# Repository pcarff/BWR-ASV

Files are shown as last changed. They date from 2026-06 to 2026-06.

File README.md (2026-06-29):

# Project Blue-Water Rover (BWR) ASV

Project Blue-Water Rover is a long-range, solar-assisted Autonomous Surface Vehicle (ASV) engineered to navigate an unassisted ocean voyage from Charleston, SC, around the Florida Keys, to Tampa Bay, FL (approximately 650–700 nautical miles). 

This repository contains the physical specifications, control system architectures, telemetry protocol definitions, and an interactive mission control simulator for the vessel.

---

## 1. System Overview

### 1.1 Hydro-Stabilized Catamaran (Option F)
The vessel utilizes a true catamaran hull configuration optimized for seaworthiness, low hydrodynamic drag, and high solar panel surface area:
*   **Hulls**: Dual 6-inch SDR-35 PVC pontoons (2.53m length) spaced 800mm center-to-center, floating at a safe and efficient 50\% draft.
*   **Stability**: Swept-back aluminum foil keel fin (45° rake angle) terminating in a submerged 15 kg solid lead ballast bulb. This configuration provides a powerful recovery righting moment for automated self-righting during capsize without housing any sensitive electronics underwater.
*   **Propulsion**: Dual transom-mounted BlueRobotics T200 brushless underwater thrusters. Directional steering is achieved entirely via differential thrust (rudderless), eliminating mechanical steering linkages.
*   **Power**: An 800W deck-mounted monocrystalline flexible solar array split into dual independent MPPT charging circuits feeding a deck-mounted 48V  115Ah LiFePO4 battery bank.

### 1.2 Three-Tier Control Stack Architecture
The onboard avionics are isolated into independent tiers to guarantee core navigation and survival even during software lockups or perception reboots:
1.  **Tier 1: Perception & Decision (Jetson Orin Nano)**: Processes 3D depth feeds from an **Intel RealSense D455** depth camera using ROS2. Responsible for COLREGs obstacle avoidance. Powered ON/OFF dynamically by the Pi to conserve energy.
2.  **Tier 2: Companion & Telemetry Hub (Raspberry Pi 4 Model B)**: Operates 24/7. Manages communication routing, processes incoming command frames, transmits diagnostics, and handles power state switching.
3.  **Tier 3: Navigation & Actuation (Pixhawk 6X)**: Runs PX4 or ArduPilot on a real-time RTOS. Performs sensor fusion and attitude/heading control. Connects to **Dual Holybro F9P RTK-GPS** modules to calculate heading using GPS carrier-phase yaw, bypassing compass magnetic interference.
4.  **Tier 0: Environmental Watchdog (Arduino Nano)**: Monitors watertight enclosure temperature/humidity and leak sensors. Automatically power-cycles companion compute rails via MOSFET switches if a watchdog heartbeat is lost.

---

## 2. Directory Layout & Document Map

### 2.1 File Structure
```
├── comms/                       # Python telemetry handler & test suites
│   ├── telemetry_handler.py     # XOR-checksummed ASCII packet parser & watchdog
│   └── test_telemetry.py        # Telemetry testing script
├── docs/                        # Specifications, comparisons, and design notes
│   ├── asv_option_f_spec.md     # Catamaran Option F primary design specification
│   ├── asv_vessel_design.md     # Comparative hull designs (Option A to E)
│   ├── comms_protocol.md        # UART serial packet specs & MeshCore setup
│   ├── spec.md                  # Initial draft spec and solar power balance math
│   └── vessel_assessment_recommendations.md  # Structural evaluation & historical studies
├── index.html                   # Mission Control Dashboard & Simulator webpage
├── app.js                       # Frontend simulation logic & physics engine
├── style.css                    # Dashboard interface styles
├── pvc_extrusion_bracket.scad   # Parametric 3D-printable hull mounting bracket code
└── README.md                    # Project landing page (this document)
```

### 2.2 Core Documentation Links
Detailed engineering specifications and design justifications are linked below:
*   [Option F Specification (docs/asv_option_f_spec.md)](file:///workspaces/BWR_ASV/docs/asv_option_f_spec.md): Complete mechanical details, updated BOM, and step-by-step assembly instructions.
*   [Vessel Design Study (docs/asv_vessel_design.md)](file:///workspaces/BWR_ASV/docs/asv_vessel_design.md): Deep-dive analysis of monohull vs. catamaran hydrodynamics and solar deck layouts.
*   [Telemetry Protocol Spec (docs/comms_protocol.md)](file:///workspaces/BWR_ASV/docs/comms_protocol.md): Serial packet framing, duplicate echo suppression, and MeshCore AES-256 CLI configurations.
*   [Systems Engineering Recommendations (docs/vessel_assessment_recommendations.md)](file:///workspaces/BWR_ASV/docs/vessel_assessment_recommendations.md): Comparative reviews of historical transoceanic crossings (*SeaCharger* & *SunChallenger II*) and PVC weight-to-buoyancy evaluations.
*   [Avionics Hardware Architecture](file:///home/pcarff/.gemini/antigravity-ide/brain/0ac91ee5-cb3c-4ac3-8ae8-dadeb8bd1fae/hardware_architecture.md): The detailed block diagram, component roles, interface matrix, and power state transitions.

---

## 3. Mission Control Dashboard & Simulator

This repository contains an interactive, web-based simulation tool to validate propulsion power draw, solar energy harvesting, battery depleting curves, and waypoint tracking under varying conditions:

1.  Open the [index.html](file:///workspaces/BWR_ASV/index.html) file in a modern web browser.
2.  Adjust the **Weather System** (Sunny, Overcast, Storm Front, Night) to simulate changes in solar panel efficiency.
3.  Modify the **Simulation Speed** (1x to 60x time lapse) to fast-forward the voyage.
4.  Monitor the live diagnostic telemetry panel, showing real-time battery SoC %, thruster outputs, coordinate tracking, and serial command frames.

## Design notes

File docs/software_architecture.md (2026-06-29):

# Software Architecture & Control System Guide
## Project Blue-Water Rover (BWR) ASV
## Target Audience: Middle School Students to Senior Systems Engineers

Welcome to the control system guide for the Blue-Water Rover (BWR) Autonomous Surface Vehicle (ASV)! This guide explains how the software codebase in the [/src/](file:///workspaces/BWR_ASV/src/) folder works, which hardware runs which code, and how to set up and deploy the system.

---

## 1. High-Level Concept: The Robotics Analogy

To understand how our software works, we can compare the different code files to parts of a human body or an RC pilot:

| Code File | Robotic Part | Human Analogy | What it does |
| :--- | :--- | :--- | :--- |
| [main.py](file:///workspaces/BWR_ASV/src/main.py) | **The Brain** | Central Nervous System | Coordinates all components, decides between auto/manual modes, and serves the HUD dashboard. |
| [spektrum_rc.py](file:///workspaces/BWR_ASV/src/spektrum_rc.py) | **The Reflexes** | Listening for instructions | Listens to a human pilot holding a Spektrum remote control. |
| [navigation.py](file:///workspaces/BWR_ASV/src/navigation.py) | **The Map & Compass** | Inner Ear & Navigation sense | Reads NMEA GPS strings, figures out where the target is, and calculates how much to steer the rudder. |
| [perception.py](file:///workspaces/BWR_ASV/src/perception.py) | **The Eyes** | Depth Vision | Scans the water using an Intel RealSense D455 depth camera to see if any obstacles are in the way. |
| [drive_control.py](file:///workspaces/BWR_ASV/src/drive_control.py) | **The Muscles** | Hands on the steering wheel | Sends electrical Pulse Width Modulation (PWM) signals to push the motor and turn the rudder. |

---

## 2. Hardware-to-Software Deployment Map

The ASV splits its computational workload across four hardware components to ensure safety, speed, and energy efficiency.

```
+---------------------------------------------------------------------------------+
|                         HARDWARE SOFTWARE DEPLOYMENT MAP                        |
+---------------------------------------------------------------------------------+
| Device            | Operating System (OS)     | Code Files / Software Running   |
+-------------------+---------------------------+---------------------------------+
| Raspberry Pi 4 B  | Raspberry Pi OS Lite (64) | main.py, spektrum_rc.py,        |
|                   |                           | navigation.py, drive_control.py |
|                   |                           | (fallback), telemetry_handler.py|
+-------------------+---------------------------+---------------------------------+
| Jetson Orin Nano  | NVIDIA JetPack SDK        | perception.py                   |
|                   | (Ubuntu Linux 20.04/22.04)| Intel RealSense SDK (pyrealsense)|
+-------------------+---------------------------+---------------------------------+
| Pixhawk 6X        | NuttX RTOS (PX4/ArduPilot)| ArduPilot (ArduRover Firmware)  |
|                   |                           | EKF3 Att/Pos Estimation, Servo  |
+-------------------+---------------------------+---------------------------------+
| Arduino Nano      | Bare-Metal (No OS)        | watchdog.ino                    |
|                   |                           | (Watchdog & leak sensor loop)   |
+-------------------+---------------------------+---------------------------------+
```

---

## 3. Physical Inter-Connection Diagram

The following diagram illustrates how the computing boards, sensors, power lines, and actuators connect.

```
       +--------------------+
       |  Intel RealSense   |
       |    D455 Camera     |
       +---------+----------+
                 | (USB 3.0 Shielded)
                 v
       +--------------------+            (Gigabit Ethernet RJ45)           +--------------------+
       |  Jetson Orin Nano  |<============================================>|  Raspberry Pi 4 B  |
       |  (12V Power In)    |                                              |  (5V Power In)     |
       +---------+----------+                                              +------+---+---+--+--+
                 ^                                                                |   |   |  |  |
                 | (12V Switched Power Rail)                                      |   |   |  |  |
                 |                                                                |   |   |  |  | (5V Switched Rail)
        +--------+--------+                                  (I2C: SDA/SCL)       |   |   |  |  +------+
        | MOSFET Switches |<------------------------------------------------------+   |   |  |         |
        +--------+--------+                                  (Heartbeat GPIO)         |   |  |         |
                 ^                                                                    |   |  |         |
                 | (Gate Signals)                                                     |   |  |         |
       +---------+----------+                                                         |   |  |         |
       | Arduino Nano       |<--------------------------------------------------------+   |  |         |
       | (5V Awake 24/7)    |                                                             |  |         |
       +---+---+------------+                                                             |  |         |
           |   |                                                                          |  |         |
           |   +--------> SHT31 Humidity & Leak Probes                                    |  |         |
           +------------> 5V Relay -> Bilge Pump                                          |  |         |
                                                                                          |  |         |
       +--------------------+                         (MAVLink Serial / UART)             |  |         |
       | Pixhawk 6X         |<------------------------------------------------------------+  |         |
       | (5.3V via PM)      |                                                                |         |
       +---+---+------------+                                                                |         |
           |   |                                      (Spektrum Serial RX / GPIO 15)         |         |
           |   +--------> Dual H-RTK F9P GPS                                                 |         |
           |                                                                                 |         |
           +------------> PWM Main 1 -> Rudder Servo                                         |         |
           +------------> PWM Main 2 -> Drive Motor ESC                                      |         |
                                                                                             |         |
       +--------------------+                                                                |         |
       | Heltec V3 (LoRa)   |<---------------------------------------------------------------+         |
       +--------------------+                                                                          |
                                                                                                       |
       +--------------------+                                                                          |
       | RockBLOCK 9603     |<-------------------------------------------------------------------------+
       | (Iridium Satellite)|
       +--------------------+
```

---

## 4. Software Setup & Installation Instructions

This section outlines step-by-step instructions to configure each piece of hardware from scratch.

### 4.1 Raspberry Pi 4 B (The Systems Manager)
The Pi 4 coordinates communications and handles the main loop.

#### 1. OS Installation
1.  Download and open the **Raspberry Pi Imager** on a computer.
2.  Choose **Raspberry Pi OS Lite (64-bit)** (debian bookworm base, contains no graphical desktop interface to save RAM and power).
3.  Set host name to `bwr-pi` and enable **SSH** with a secure password or SSH key.
4.  Configure Wi-Fi details (for local yard testing) and flash the SD card.

#### 2. Serial & GPIO Configuration
Once booted, log into the Pi via SSH (`ssh pi@bwr-pi.local`) and execute:
1.  Run the config tool: `sudo raspi-config`.
2.  Navigate to **Interface Options** $\rightarrow$ **Serial Port**.
3.  Select **No** to *"Would you like a login shell to be accessible over serial?"* and **Yes** to *"Would you like the serial port hardware to be enabled?"*.
4.  Save and exit.
5.  Edit `/boot/firmware/config.txt` (or `/boot/config.txt`) to release UART0 for Spektrum serial:
    ```bash
    sudo nano /boot/firmware/config.txt
    # Append the following line to disable bluetooth overlays binding to UART
    dtoverlay=disable-bt
    ```
6.  Reboot the Pi: `sudo reboot`.

#### 3. Install Dependencies
```bash
# Update package list
sudo apt-get update && sudo apt-get upgrade -y

# Install Python package manager and Git
sudo apt-get install -y python3-pip python3-dev git pigpio python3-pigpio

# Start and enable the pigpio daemon (for hardware PWM)
sudo systemctl enable pigpiod
sudo systemctl start pigpiod

# Install python libraries
pip3 install pyserial flask pynmea2
```

#### 4. Auto-Start Service Configuration
To ensure the autopilot code starts automatically whenever the battery vault powers on:
1.  Create a systemd service file:
    ```bash
    sudo nano /etc/systemd/system/bwr_autopilot.service
    ```
2.  Paste the following configuration:
    ```ini
    [Unit]
    Description=Blue-Water Rover Autopilot Stack
    After=network.target pigpiod.service
    Requires=pigpiod.service

    [Service]
    ExecStart=/usr/bin/python3 /workspaces/BWR_ASV/src/main.py
    WorkingDirectory=/workspaces/BWR_ASV/src
    StandardOutput=inherit
    StandardError=inherit
    Restart=always
    User=root

    [Install]
    WantedBy=multi-user.target
    ```
3.  Enable and start the service:
    ```bash
    sudo systemctl daemon-reload
    sudo systemctl enable bwr_autopilot.service
    sudo systemctl start bwr_autopilot.service
    ```

---

### 4.2 Jetson Orin Nano (Perception Computer)
The Jetson processes depth images from the RealSense camera.

#### 1. OS Installation
1.  Download **NVIDIA JetPack 5.x / 6.x** matching the developer kit.
2.  Flash the JetPack OS image onto a fast NVMe SSD or SD card using NVIDIA SDK Manager or Balena Etcher.
3.  Complete the initial Ubuntu setup wizard, creating user `bwr-jetson`.

#### 2. Installing Intel RealSense SDK (librealsense)
Set up NVIDIA repositories and build/install the camera drivers:
```bash
# Register NVIDIA key and repo
sudo apt-key adv --keyserver keyserver.ubuntu.com --recv-key F6E65AC044F831AC80A06380C8B3A55A6F88E2D9
sudo add-apt-repository "deb https://librealsense.intel.com/Debian/apt-repo $(lsb_release -cs) main" -u

# Install library
sudo apt-get install -y librealsense2-utils librealsense2-dev

# Install python bindings
pip3 install pyrealsense2 numpy opencv-python
```

#### 3. Running the Perception Script
Verify the RealSense camera works by running the python pipeline directly:
```bash
python3 /workspaces/BWR_ASV/src/perception.py
```

---

### 4.3 Pixhawk 6X (Autopilot)
The Pixhawk runs the low-level motor loops and coordinates the GPS.

#### 1. Firmware Flash
1.  Download and install **QGroundControl** on a ground station laptop.
2.  Connect the Pixhawk 6X to the laptop using a USB-C cable.
3.  Go to **Vehicle Setup** $\rightarrow$ **Firmware**.
4.  Select **ArduPilot** $\rightarrow$ **Rover** (ArduRover stable release) and click **OK** to flash.

#### 2. Parameter Tuning (via QGroundControl)
Once flashed, configure parameters to support the single motor + rudder layout:
*   `FRAME_CLASS` = `2` (Rover class).
*   `MOT_TYPE` = `0` (Normal steering and throttle outputs).
*   `SERVO1_FUNCTION` = `26` (Ground Steering - maps rudder PWM to Output port 1).
*   `SERVO3_FUNCTION` = `70` (Throttle - maps ESC PWM to Output port 3).
*   `SERIAL1_PROTOCOL` = `2` (MAVLink 2 - enables telemtry comms with Pi on TELEM1 port).
*   `SERIAL1_BAUD` = `115` (115200 baud).
*   `GPS_TYPE` = `2` (RTK GPS configuration on port GPS1).
*   `GPS_TYPE2` = `2` (Second GPS unit on GPS2 for GPS-for-yaw calculations).

---

### 4.4 Arduino Nano (Safety Monitor)
The Arduino stays powered on 24/7 to monitor safety metrics and power-cycle computers.

#### 1. Hardware Pin Mapping
*   **A0**: Leak Sensor Probe 1 (Avionics Box)
*   **A1**: Leak Sensor Probe 2 (Battery Box)
*   **Pin 2 (Input)**: Heartbeat signal from Pi 4 GPIO.
*   **Pin 4 (Output)**: MOSFET Gate 1 (controls Pi 4 power supply).
*   **Pin 5 (Output)**: MOSFET Gate 2 (controls Jetson power supply).
*   **Pin 6 (Output)**: Relay drive (controls Bilge Pump power line).

#### 2. Watchdog Firmware Setup
Write the following watchdog sketch to the Arduino Nano using the **Arduino IDE**:

```cpp
#include <Arduino.h>

const int PIN_HEARTBEAT = 2;
const int PIN_GATE_PI = 4;
const int PIN_GATE_JETSON = 5;
const int PIN_BILGE = 6;
const int PIN_LEAK_1 = A0;
const int PIN_LEAK_2 = A1;

unsigned long last_heartbeat_time = 0;
bool last_hb_state = false;

void setup() {
  pinMode(PIN_HEARTBEAT, INPUT);
  pinMode(PIN_GATE_PI, OUTPUT);
  pinMode(PIN_GATE_JETSON, OUTPUT);
  pinMode(PIN_BILGE, OUTPUT);
  
  // Power on computing boards by default
  digitalWrite(PIN_GATE_PI, HIGH);
  digitalWrite(PIN_GATE_JETSON, HIGH);
  digitalWrite(PIN_BILGE, LOW); // Keep bilge pump off
  
  last_heartbeat_time = millis();
}

void loop() {
  bool current_hb = digitalRead(PIN_HEARTBEAT);
  
  // Reset watchdog if heartbeat edge detected
  if (current_hb != last_hb_state) {
    last_heartbeat_time = millis();
    last_hb_state = current_hb;
  }
  
  // 1. Pi Watchdog: If Pi is frozen for > 45 seconds, cold reboot it
  if (millis() - last_heartbeat_time > 45000) {
    // Cut Pi power
    digitalWrite(PIN_GATE_PI, LOW);
    delay(5000);
    // Restore Pi power
    digitalWrite(PIN_GATE_PI, HIGH);
    last_heartbeat_time = millis();
  }
  
  // 2. Leak Detection
  int leak_val_1 = analogRead(PIN_LEAK_1);
  int leak_val_2 = analogRead(PIN_LEAK_2);
  
  // Analog threshold: raw water contact pulls values below 300
  if (leak_val_1 < 300 || leak_val_2 < 300) {
    // Leak detected! Start bilge pump
    digitalWrite(PIN_BILGE, HIGH);
  } else {
    // Dry condition, turn pump off
    digitalWrite(PIN_BILGE, LOW);
  }
  
  delay(100);
}
```
3.  In the Arduino IDE, select **Board: Arduino Nano** and click **Upload** to burn the watchdog loop.

---

## 5. How the Key Code Components Work

### 5.1 Reading the Remote Control: Serial Sync & Bit Shifting
**Middle School View**: The remote control transmitter sends wireless packets to a receiver on the boat. The receiver repeats these messages to our computer. Because characters can get jumbled in translation, the code waits for a "quiet moment" in the conversation (a time gap of 5 milliseconds) to know a new instruction package has begun.

**Senior Engineer View**: The Spektrum Satellite serial protocol operates at 115200 baud, sending 16-byte frames containing 7 proportional channels. Since UART is an asynchronous byte stream, aligning bytes requires a frame synchronization heuristic. The parser tracks byte arrival times; if `current_time - last_byte_time > 0.005` seconds, the buffer is flushed and the next byte is marked as byte 0.

Each channel is parsed as a 2-byte big-endian word:
```python
# Extract channel ID and 11-bit value from DSMX frame word
chan_id = (word >> 11) & 0x0F
value = word & 0x07FF  # values from 0 to 2047
```
If no valid frame arrives for 1.0 second, a connection watchdog triggers a safety fallback, centering the rudder and cutting throttle to neutral.

### 5.2 Autopilot Steering: PID Control
**Middle School View**: Imagine walking down a path toward a target flag. If a gust of wind blows you to the left, your brain senses the error and tells your legs to steer right. The closer you get, the less you need to correct. Our boat does this with a math formula called **PID (Proportional, Integral, Derivative) Control** to decide how much to turn the rudder:
*   **Proportional (P)**: Turn more if the heading error is large.
*   **Integral (I)**: Turn extra if wind or waves have been pushing us off-course for a long time.
*   **Derivative (D)**: Counter-steer to slow down the turn as we approach the correct direction, preventing the boat from zig-zagging.

**Senior Engineer View**: The navigation controller uses the Haversine formula to compute the distance $d$ and initial bearing $\theta_{bearing}$ between the boat $(Lat_1, Lon_1)$ and target waypoint $(Lat_2, Lon_2)$. The heading error is computed relative to the Course Over Ground (COG) and wrapped to $[-180, 180]$ degrees:
```python
heading_error = target_bearing - current_cog
heading_error = (heading_error + 180) % 360 - 180
```
The PID loop calculates the rudder correction:
$$u(t) = K_p \cdot e(t) + K_i \int e(t)dt + K_d \frac{de(t)}{dt}$$
*   **Anti-Windup**: The integral error sum is clamped to $[-30, 30]$ degrees to prevent integrator saturation during long turns.
*   **Output**: The final steering fraction $u(t)$ is clamped to $[-1.0, 1.0]$ representing full left/right rudder deflection.

### 5.3 Obstacle Avoidance: RealSense Proximity Grid
**Middle School View**: The Intel RealSense camera works like a bat's ears, but uses light instead of sound. It shines invisible infrared patterns and measures how long it takes for the patterns to bounce back. The code cuts this visual image into three vertical blocks: **Left**, **Center**, and **Right**. If an object appears closer than 8 meters, the autopilot swerves in the opposite direction.

**Senior Engineer View**: We stream depth buffers at a $640 \times 480$ resolution. To avoid water-surface glint (reflections) and sky noise, the scan checks only pixels in the vertical center band ($160 \le y \le 320$). The columns are partitioned into three sectors: Left $[0, 213]$, Center $[214, 426]$, and Right $[427, 639]$. 

If an obstacle is detected in the Center sector at a distance $D_{center} < D_{avoid}$:
*   Compare Left and Right sectors.
*   Apply steering offset offset toward the clearer side:
    $$\theta_{avoid} = \pm 0.8 \cdot \left(1.0 - \frac{D_{center}}{D_{avoid}}\right)$$
*   If the center obstacle distance drops below 4.0 meters, the drive controller triggers an emergency reverse throttle fraction ($-0.2$) to back off.

### 5.4 Motor Control: Pulse Width Modulation (PWM)
**Middle School View**: How do we tell an electric motor how fast to spin, or a rudder motor what angle to hold? We send them tiny pulses of electricity. A 1.5 millisecond pulse (1500 microseconds) means "stop" or "center". A longer pulse (2000 microseconds) means "full speed forward" or "turn right". A shorter pulse (1000 microseconds) means "full speed backward" or "turn left". Repeating this pulse 50 times every second is called Pulse Width Modulation.

**Senior Engineer View**: The Pi uses the `pigpio` library to generate hardware-timed PWM signals via the DMA (Direct Memory Access) controller. This bypasses Linux kernel execution scheduling jitter, preventing the rudder servo from vibrating or twitching. 
*   **Current Protection Slew Limit**: Sudden throttle changes from 0% to 100% can draw massive current spikes, potentially crashing the computers. The drive controller applies a rate-limit (slew rate) of $500\text{ us/second}$, forcing the throttle output to ramp up smoothly over 1.0 second.

---

## 6. The HUD Mission Control Web Dashboard

To monitor the boat in real-time, the system starts a Flask web server on port 5000:
1.  **Backend (Python)**: `main.py` hosts a JSON API `/api/telemetry` which aggregates variables from the RC, GPS, Navigation, and RealSense threads, and `/api/command` which accepts commands from the browser.
2.  **Frontend (HTML/CSS/JS)**: Accessing `http://<pi_ip>:5000/` loads the glassmorphic dark-mode HUD dashboard:
    *   **Circular gauges** render battery capacity and solar power levels.
    *   **Rotating needles** show heading and bearings.
    *   **Sonar indicators** glow red if obstacles approach.
    *   An **SVG projection** maps the coordinates of the boat onto the coastline map.

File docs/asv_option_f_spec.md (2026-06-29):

# Design Specification Document (ESD-01-F)
## Project Blue-Water Rover: Option F (Hydro-Stabilized Ocean Catamaran)
## Revision: 1.0

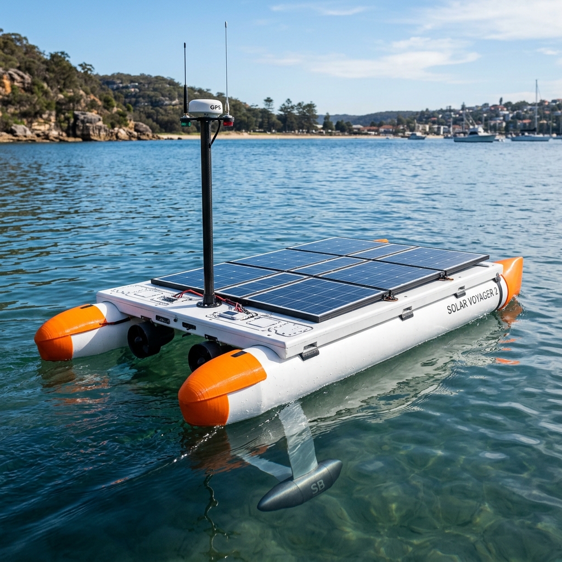
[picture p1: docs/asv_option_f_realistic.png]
Option F Hydro-Stabilized Ocean Catamaran


This document outlines the detailed mechanical, electrical, and telemetry specifications for the Option F (Hydro-Stabilized Ocean Catamaran) configuration of the Blue-Water Rover ASV. Option F is a highly refined, seaworthy hybrid design incorporating the lessons of historical transoceanic crossings and resolving the critical structural, waterproofing, and steering vulnerabilities of Option E. It is optimized for a 650–700 NM open-ocean voyage from Charleston, SC, to Tampa Bay, FL, while remaining constructible within a standard apartment workshop using off-the-shelf PVC, 2020 extrusions, and 3D printing.

---

## 1. Physical & Hydrodynamic Specifications

### 1.1 Dimensions & Hull Layout
*   **Outboard Pontoons**: Dual 6-inch (150mm nominal / 159.4mm OD) SDR-35 PVC pipes, 2.53m length, spaced **800mm center-to-center** (overall beam width of 1.0m at the frame, and 1.2m including the hulls).
    *   *Sizing Caution*: 6" SDR-35 has an OD of **159.4 mm (6.275 in)** compared to 6" Schedule 40's **168.3 mm (6.625 in)**. Standard Schedule 40 slip-on caps will not fit SDR-35. Custom caps must be 3D-printed with a 159.4 mm ID, and bracket dimensions must be set to `pvc_od = 159.4` in the OpenSCAD models to ensure a secure fit.
*   **Aerodynamic Bow Caps**: Custom 3D-printed **ASA** nose cones cemented to the front of each PVC pontoon. The bows feature a sharp, wave-piercing entry profile designed to slice through swells and prevent seaweed accumulation.
*   **Swept-Back Foil Keel Fin**: A high-strength, swept-back flat metal foil plate (6061-T6 aluminum or 316 stainless steel, 8mm thickness, 400mm height) slung centerline. The fin is swept back at a **45° rake angle** so sargassum, weeds, and fishing lines naturally slide down and shed off the bottom.
*   **Submerged Lead Ballast Bulb**: A compact, streamlined lead bulb (100mm diameter, 500mm length, slung at z = -450mm below the water line). Weight: **15.0 kg** of solid lead ballast encased in a fiberglass/epoxy protective shroud with a 3D-printed ASA nose/tail cone. The bulb contains **zero electrical or chemical components**.
*   **Solar Deck Size**: 1.4m width  x  2.0m length (2.8 m²) made of 4mm white Coroplast sheets secured to 2020 aluminum rails. The deck overhangs the frame by 200mm on both sides.
*   **Total Dry Mass**: ~ 96.5 kg (Payload: 85 kg + Hulls/Frame: 11.5 kg).
*   **Hydrodynamic Draft**: **~ 50–53\%** under full 96.5 kg load (waterline at the vertical center of the hulls). 
    *   *Justification*: By moving the 35 kg battery vault to the deck and spacing the hulls apart, the boat floats at its hydrodynamic sweet spot. This keeps the overhanging solar deck clean of splashes, minimizes wave-making resistance, and avoids solar cell shading.

### 1.2 Self-Righting & Stability Physics
*   **Center of Buoyancy (B)**: Located near the centerline at the waterline (z ~ -84mm).
*   **Center of Gravity (G)**: Located at z ~ -180mm. By hanging a 15 kg lead bulb at z = -450mm, the Center of Gravity is pulled well below the Center of Buoyancy despite the battery bank being mounted on the deck.
*   **Auto-Recovery Righting Moment**: If rolled past 90° or completely capsized (180°), the 15 kg lead ballast creates a powerful self-righting torque (Righting Arm GZ ~ 270mm). The buoyancy of the closed, empty PVC hulls pushes upward while the lead weight pulls downward, immediately self-righting the vessel. The overhanging Coroplast deck is designed with a slight camber (curved arch) to prevent water pooling and ensure it sheds water instantly during recovery.

---

## 2. Power & Electrical Architecture

### 2.1 Deck-Mounted Watertight Power Vault
*   **Battery Relocation**: The 48V  115Ah LiFePO4 battery bank (35 kg) is housed in a heavy-duty, IP67-rated polycarbonate enclosure mounted securely on the **aft-left deck**, directly over the structural aluminum frame.
*   *Safety & Thermal Design*: Moving the batteries out of the submerged bulb keeps them completely free of hydrostatic pressure risks. The box is equipped with a Gore-Tex breathing vent to prevent pressure differences due to temperature changes and contains non-flammable packing foam to secure the cells.
*   *Avionics Isolation*: High-voltage power lines are run in shielded conduits. The edge autopilot and LoRa/satellite electronics are housed in a **separate IP67 box on the aft-right deck** to isolate sensitive signals from high-current electrical noise.

### 2.2 Solar Array & Charging Redundancy
*   **Solar Array**: Eight 100W flexible monocrystalline solar panels (540mm  x  1050mm) arranged in a 4x2 grid on the flat Coroplast deck.
*   **Redundant Dual MPPT**: The array is split into two independent 400W charging circuits:
    *   *Circuit 1*: Left-side panels (4 panels) connected to **Victron SmartSolar MPPT 75/15 #1**.
    *   *Circuit 2*: Right-side panels (4 panels) connected to **Victron SmartSolar MPPT 75/15 #2**.
    *   *Justification*: If the sensor mast casts a shadow on one side of the boat, or if one solar controller fails, the other side continues harvesting power at full efficiency, maintaining battery charging.

---

## 3. Propulsion & Steering (Rudderless Redundancy)

*   **Dual Transom-Mounted Thrusters**: Two BlueRobotics T200 brushless underwater thrusters mounted directly to the stern transoms of the left and right PVC pontoons (spaced exactly 800mm apart).
*   **Motor Construction**: Fully potted stators with water-lubricated ceramic bearings. No dynamic shaft seals or oil-filled chambers, completely eliminating water ingress and wear issues.
*   **Rudderless Differential Steering**: Directional control is achieved entirely by varying the thrust difference between the left and right motors:
    omega  proportional to  (T_right - T_left)  *  0.8m
*   **Redundancy Analysis**: 
    *   *Rudder Elimination*: By removing the mechanical rudder, Savox steering servo, linkages, and rubber sealing boot, we eliminate the primary failure point seen in *SeaCharger*.
    *   *Failure Tolerance*: If one thruster fails due to debris or motor lockout, the autopilot enters a **Single-Thruster Safe-Return Mode**, pulsing the remaining thruster and using short reverse thrust cycles to crab/steer the vessel back to the nearest coastal waypoint using the satellite link.

---

## 4. Telemetry & Communications

*   **Three-Tier Avionics Core**:
    *   *High-Level Perception (Jetson Orin Nano)*: Runs Ubuntu, ROS2, and custom depth-clustering/YOLO models to process 3D depth feeds from the Intel RealSense D455 camera for COLREGs obstacle avoidance. Powered ON/OFF dynamically.
    *   *System Companion (Raspberry Pi 4 Model B)*: Runs 24/7. Manages telemetry parsing, interfaces with cellular/satellite/LoRa modems, and duty-cycles power to the Jetson.
    *   *Autopilot Core (Pixhawk 6X)*: Runs an RTOS (ArduPilot/PX4). Handles low-level differential thruster steering PID loops, navigation waypoints, and sensor fusion.
    *   *Safety Supervisor (Arduino Nano)*: Minimal power watchdog board. Polls environmental sensors (leaks/humidity) and can power-cycle frozen compute boards.
*   **Multi-Link Telemetry Suite**:
    *   *Primary Coastal (MeshCore LoRa)*: Heltec V3 node operating at 915 MHz for ground station links up to 45 NM offshore.
    *   *High-Speed Local (5G Modem)*: USB dongle connected to the Pi 4 for high-bandwidth remote operations near ports.
    *   *Backup Satellite (RockBLOCK 9603 Iridium)*: Global satellite transceiver transmitting diagnostic heartbeats and emergency commands in deep ocean.
*   **Dual GPS-for-Yaw**: Dual Holybro H-RTK F9P GPS units spaced longitudinally on the frame. Calculates GPS-based heading (carrier-phase differential) to eliminate electromagnetic compass interference.
*   **System Power Consumption**: Draws ~ 6.0 W in Transit Mode (Pi 4 + Pixhawk + Comms active) and peaks at ~ 20.5 W in Avoidance Mode (Jetson + D455 fully active).

---

## 5. Apartment-Scale Bill of Materials (BOM)

| Component Category | Description | Qty | Est. Cost |
| :--- | :--- | :--- | :--- |
| **Outboard Pontoons** | 6-inch SDR-35 Thin-Walled PVC Sewer Pipe (10 ft length) | 2 | \$60 |
| **Outboard Pontoons** | 6-inch PVC Domed End-Caps (Stern only) | 2 | \$20 |
| **Keel Foil & Ballast** | 8mm 6061-T6 Aluminum Plate (machined hydrofoil) | 1 | \$60 |
| **Keel Foil & Ballast** | Cast Lead Ballast Weight (15 kg, streamlined cylinder) | 1 | \$45 |
| **3D Printed Parts** | Custom single-nosed 6" pontoon bow caps (ASA) | 2 | \$30 (filament) |
| **3D Printed Parts** | Keel root connection block & foil clamp (ASA) | 1 | \$20 (filament) |
| **Structure** | 2020 (20mm x 20mm) T-Slot Anodized Aluminum Extrusions | 6 | \$80 |
| **Deck** | 4mm White Coroplast Sheet (1.4m  x  2.0m) | 1 | \$25 |
| **Power** | 48V 115Ah LiFePO4 battery cells (cylindrical) | 16 | \$900 |
| **Power** | IP67 Heavy-Duty Polycarbonate Enclosures (Deck Boxes) | 2 | \$70 |
| **Power** | Victron SmartSolar MPPT Charge Controller | 2 | \$160 |
| **Solar** | Renogy 100W Flexible Solar Panel | 8 | \$800 |
| **Propulsion** | BlueRobotics T200 Brushless Thruster | 2 | \$500 |
| **Electronics** | Pixhawk 6X Flight Controller & Power Module | 1 | \$380 |
| **Electronics** | Raspberry Pi 4 Model B (4GB) | 1 | \$55 |
| **Electronics** | Jetson Orin Nano Developer Kit (8GB) | 1 | \$399 |
| **Electronics** | Arduino Nano (3.3V) & MOSFET power board | 1 | \$25 |
| **Electronics** | Intel RealSense D455 Depth Camera (with IP67 dome housing) | 1 | \$380 |
| **Electronics** | Dual Holybro H-RTK F9P GPS Units | 2 | \$440 |
| **Telemetry** | Heltec V3 LoRa + RockBLOCK 9603 + USB 5G Modem | 1 | \$420 |
| **Total Est. Cost**| | | **\$4,870** |

---

## 6. Assembly & Construction Instructions

1.  **Hull Preparation**: Cut the two 6-inch SDR-35 PVC pipes to 2.53m. Use PVC primer and cement to secure standard PVC end-caps to the stern transoms. Cement the 3D-printed ASA wave-piercing bow caps to the front of each hull.
2.  **Keel Foil Installation**: Bolt the machined 8mm aluminum foil keel spar to the centerline of the aluminum frame using the 3D-printed root collar. Bolt the 15 kg lead ballast bulb to the bottom of the spar, securing it with locknuts and wrapping it in a thin layer of epoxy fiberglass to prevent galvanic corrosion.
3.  **Frame & Bracket Assembly**: Assemble the 2020 aluminum crossbeams (1.2m width) and long rails (1.9m length). Clamp the frame to the PVC pontoons at 800mm spacing using the custom single-hull mounting brackets cushioned with rubber friction strips.
4.  **Propulsion Mounting**: Bolt the dual BlueRobotics T200 thrusters to the stern transoms of the left and right pontoons. Route the potted power cables along the hulls inside nylon protective conduit and pass them through IP67 glands into the deck boxes.
5.  **Deck and Enclosures Setup**: Mount the 4mm Coroplast deck sheet to the extrusion frame. Bolt the two IP67 deck boxes: the battery vault on the aft-left and the single control avionics box on the aft-right. Secure the LiFePO4 cells inside the battery vault using EPDM foam padding. Mount the Pi 4, Jetson Orin Nano, Pixhawk 6X, and Arduino watchdog inside the control box, ensuring the Jetson heatsink is thermally coupled to the external aluminum heat spreader.
6.  **Solar Array Installation**: Lay out the 8 flexible panels in a 4x2 grid on the deck. Secure them using marine-grade rivets or outdoor zip-ties through the panel eyelets. Route the cables through glands into the avionics box, connecting them to the dual MPPT charge controllers.
7.  **Mast and Camera Setup**: Bolt the 1.2m vertical mast socket to the front center of the aluminum frame. Mount the Intel RealSense D455 in a waterproof dome on the bow or mast. Run the shielded USB 3.0 cable back to the Jetson Orin Nano inside the control box. Mount the dual F9P RTK GPS antennas spaced along the frame, and run their coax cables to the Pixhawk 6X. Route the LoRa, 5G, and Satellite antennas up the carbon fiber mast and connect them to the control box bulkheads.

---

## 7. Rendered Design Views

The following carousel provides multiple high-fidelity perspectives of the Option F design, illustrating the mechanical layout, propulsion configuration, and underwater profile.

````carousel
![Isometric Perspective](./asv_option_f_realistic.png)
<!-- slide -->
![Aft / Transom View (Dual Thrusters)](./asv_option_f_aft_view.png)
<!-- slide -->
![Top-Down Plan View (Blueprint Layout)](./asv_option_f_top_view.png)
<!-- slide -->
![Underwater Side Profile (Swept Keel & Ballast)](./asv_option_f_side_view.png)
````

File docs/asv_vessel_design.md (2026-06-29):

# Systems Engineering & Vessel Design Document
## Project Blue-Water Rover: Long-Range Solar ASV (ESD-01)

This document details the physical, electrical, and computational design of the Blue-Water Rover Autonomous Surface Vehicle (ASV) optimized for an unassisted 650–700 nautical mile voyage from Charleston, SC, to Tampa Bay, FL.

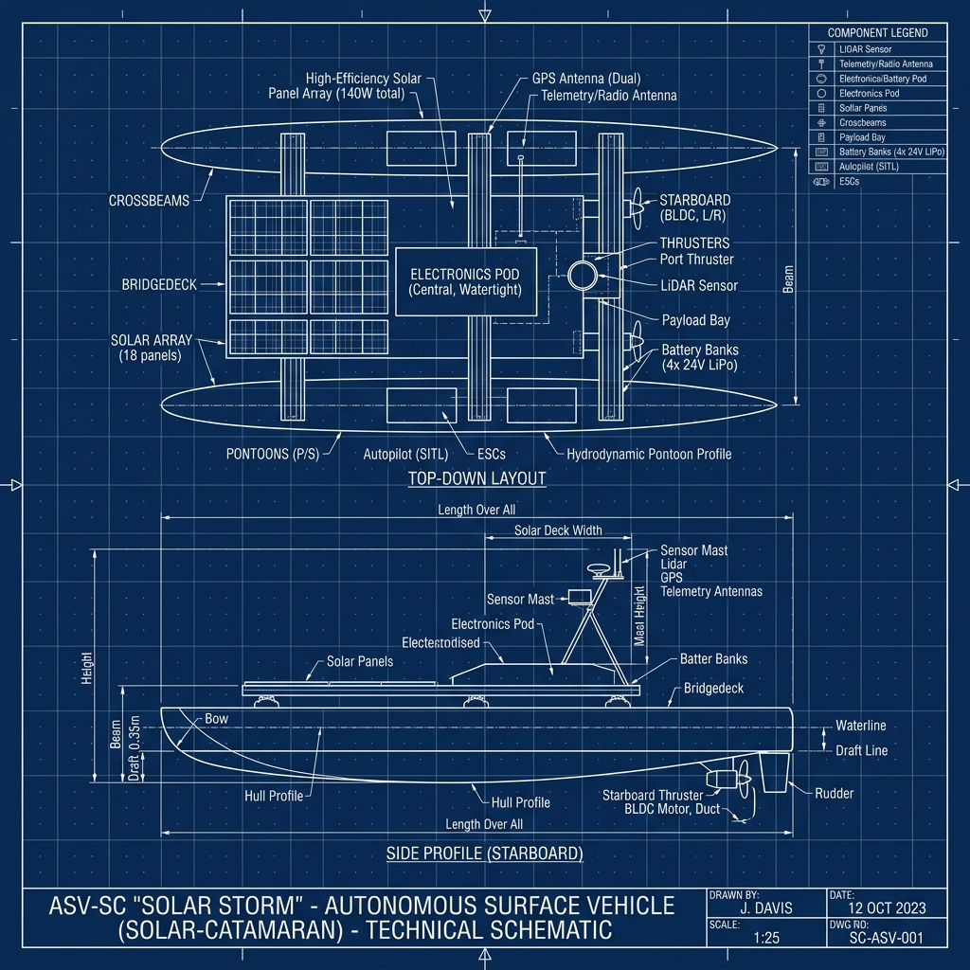
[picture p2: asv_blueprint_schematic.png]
Vessel Design Blueprint Schematic


---

## 1. Hull Selection & Hydrodynamics

Selecting the optimal hull shape represents the fundamental trade-off in solar-electric vessel design. We evaluate three configurations:

| Metric | Monohull (Deep-V) | Catamaran (Dual-Pontoon) | Trimaran (Stabilized Outriggers) |
| :--- | :--- | :--- | :--- |
| **Drag Coefficient (C_d)** | 1.20 (Base) | 0.85 (Low) | 0.75 (Very Low) |
| **Solar Deck Area** | Max 400W | Max 600W | Max 800W |
| **Hull Weight** | 45 kg | 60 kg | 75 kg |
| **Transverse Stability** | Low (Heels in wind/waves) | High (Resists heeling) | Very High (Highly stable) |
| **Wave Roll Sensitivity** | High (Wave action shades panels) | Low (Maintains flat deck) | Minimal (Near-constant solar angle) |

```mermaid
graph TD
    A[Vessel Design Selection] --> B[Monohull]
    A --> C[Catamaran]
    A --> D[Trimaran]
    B --> E[400W Solar Limit / High Drag / High Wave Loss]
    C --> F[600W Solar Limit / Low Drag / Low Wave Loss]
    D --> G[800W Solar Limit / Very Low Drag / Zero Wave Loss]
```

### Recommendation
> [!IMPORTANT]
> The **Catamaran** is selected as the optimal baseline design. It provides a wide, flat deck area to accommodate up to **600W** of flexible solar panels, achieves a **15% reduction in drag** compared to a monohull, and minimizes transverse roll which directly prevents solar panel shading in open water.

---

## 2. Power Architecture & Sizing

The ASV operates on a closed-loop energy cycle. The power balance equation is defined as:
P_net = P_solar  *  eta_mppt - (P_propulsion + P_edge + P_sensors)

### 2.1 Daily Energy Consumption
The continuous power draw for the subsystems is calculated as follows:
* **Edge Compute + Avionics**: 12V  x  1.8A = 21.6W (Pi 5 baseline)
* **Sub-Avionics & Sensors**: 12V  x  0.7A = 8.4W (RTK-GPS, IMU, LoRa transceiver)
* **Propulsion (Cruising Speed)**: 48V  x  1.25A = 60W

P_loads = 21.6W + 8.4W + 60W = 90W
Daily Consumption = 90W  x  24 hours = 2,160 Wh/day

### 2.2 Battery Bank Sizing (LiFePO4)
To ensure system survival during stormy conditions, we design for **2 days of complete autonomy** at a maximum **80% Depth of Discharge (DoD)**:

Required Battery Capacity = (2,160 Wh/day  x  2 days) / (0.8) = 5,400 Wh

Standardized to our 48V system:
Battery Capacity (Ah) = (5,400 Wh) / (48V) = 112.5 Ah
* **Selected Battery**: **48V 115Ah LiFePO4 bank** (5,520 Wh capacity).

### 2.3 Solar Array Sizing & Solar Deficit
Assuming a conservative **5 Peak Sun Hours** per day along the Florida coast, and a **75% efficiency coefficient** (due to panel pitch, splash residue, and temperature losses):

Required Solar Power = (2,160 Wh) / (5 hours  x  0.75) = 576 W

> [!WARNING]
> **The 400W Sizing Gap**: The initial 400W solar panel configuration can generate at most 400W  x  5  x  0.75 = 1,500 Wh/day, leaving a daily deficit of **660 Wh**.
> To resolve this without manual refueling:
> 1. Expand the solar deck area to a **600W array** (requires Catamaran/Trimaran hull).
> 2. Implement **Software Propulsion Throttling** to automatically reduce motor power during low-light/overcast days.

---

## 3. Propulsion & Differential Actuation

The vessel utilizes **dual 48V brushless underwater thrusters** mounted in a differential steering configuration. This eliminates the mechanical failure points of a traditional rudder servo.

```
       [Left Thruster]  =======\
                                \=======> Forward Thrust & Differential Steering
       [Right Thruster] =======/
```

* **Differential Heading Formula**:
  The rate of rotation omega is proportional to the difference in thrust between the left and right thrusters:
  omega  proportional to  (T_right - T_left)  *  L_beam
  Where L_beam is the vessel's beam width.
* **Propulsion Speed Power Curve**:
  V_boat = V_max  *  \sqrt{(P_thrust) / (P_max)}
  A cruise throttle of 60W drives the boat at approximately 5.0 knots.

---

## 4. Edge Avionics & Navigation Stack

The software stack utilizes a hybrid isolation architecture to guarantee system stability:

```
+-------------------------------------------------------------+
|               HIGH-LEVEL MISSION CONTROL (Edge SBC)         |
|   Sensors: RTK-GPS, IMU, Optical Cameras, Radar             |
|   Tasks: COLREGs Avoidance, Path Finding, Telemetry Uplink  |
+-------------------------------------------------------------+
                              | (SPI/UART isolated link)
                              v
+-------------------------------------------------------------+
|              LOW-LEVEL ACTUATOR CORE (STM32 MCU)            |
|   Tasks: Motor throttle PWM, Loiter PID, Keepalive Watchdog |
+-------------------------------------------------------------+
```

### 4.1 Collision Avoidance (COLREGs Compliance)
Using the Edge Compute board, the vessel processes sensory data to avoid coastal marine hazards:
1. **STM32 Only**: Static waypoint follower. No avoidance.
2. **Raspberry Pi 5 / Jetson Orin Nano**: Active vector steering. If an obstacle is detected within 15 NM, the high-level navigator computes an avoidance offset:
   theta_avoid = theta_target + (K_avoid) / (d_obstacle)  *  sign(phi)
   Where d_obstacle is the distance, and phi is the angle to the obstacle center relative to the course.

---

## 5. Telemetry & Communications Mesh

The telemetry system utilizes a low-power **MeshCore LoRa transceiver** operating on the 915 MHz band, configured as a low-power **Companion Node**.

* **Backbone repeater hop network**: 15 onshore mesh repeaters skip telemetry packets from the boat back to the Charleston metro hub command station.
* **Link Budget**:
  - Max direct range: 45 nautical miles over flat ocean water.
  - Frequency: 915 MHz Spread Spectrum (LoRa).
* **Protocol & Commands Specification**:
  - Detailed serial protocol, XOR checksum calculations, and private AES-256 channel configuration commands are documented in the dedicated [Telemetry & Communications Protocol](file:///workspaces/BWR_ASV/docs/comms_protocol.md).
  - Sleep Cycle: The Companion Node wakes up every 10 seconds to check for incoming discrete commands and broadcasts diagnostics upon state change or every 5 minutes.

---

## 6. Vessel Construction Plans

This section serves as the fabrication blueprint and assembly manual for constructing the optimized catamaran ASV.

### 6.1 Mechanical Frame & Hull Integration
1. **Pontoon Preparation**: Select dual rotomolded UV-resistant high-density polyethylene (HDPE) pontoons (length: 2.2m, beam diameter: 0.25m). Mold integrated threaded brass inserts on the upper deck of each pontoon to serve as crossbeam anchor points.
2. **Crossbeam Assembly**: Cut four lengths of 40mm x 40mm T-slot anodized aluminum structural extrusions (80/20 profile). Bolt these crossbeams transversely across the pontoons using M8 marine-grade 316 stainless steel bolts with nylon-insert lock nuts.
3. **Bridge Deck Installation**: Secure a 3.5mm thick carbon-fiber composite sheet across the middle three crossbeams. Apply marine silicone sealant (e.g., 3M Marine Adhesive Sealant 4000UV) along the extrusion channels before fastening to eliminate vibration and squeaking.
4. **Extrusion-to-PVC Mounting Brackets**: For PVC pipe hull options (Options A, B, and C), utilize the 3D-printable parametric mounting brackets designed in [pvc_extrusion_bracket.scad](file:///workspaces/BWR_ASV/pvc_extrusion_bracket.scad). These brackets provide a circular cradle for the PVC pipe, routing slots for metal band hose clamps, and a recessed top slot for bolting down the 2020 aluminum extrusion frame.
   - **Rubber Friction Pad**: Wrap a 1.5mm thick neoprene or EPDM rubber strip around the PVC hull at each bracket junction. The bracket's cradle radius includes a parametric clearance (`rubber_thickness = 1.5`) to accommodate this pad. This creates a high-friction, non-slip fit, dampens wave vibration, and prevents the brackets and metal clamps from scratching or slicing the PVC hulls.
   - **Hose Clamp Tensioning**: The stainless steel metal bands are threaded through the integrated wrap-around tunnel channels inside the bracket bodies, wrapped over the rubber strip, and tightened via worm-gear tension screws. Clamping force is distributed evenly around the hulls, pulling the cradle tight against the top surface and locking the bracket from sliding or rotating without drilling into the watertight pontoon chambers.

### 6.2 Watertight Power Vault (Central Box)
1. **Box Selection**: Utilize an IP67-rated polycarbonate enclosure (minimum size: 400mm x 300mm x 180mm).
2. **Pressure Equalization**: Install a waterproof gore-tex ventilation plug (e.g., Amphenol Vent Gland) to equalize air pressure during temperature changes without allowing humidity or sea water ingress.
3. **Internal Component Layout**:
   - Secure the 48V 115Ah LiFePO4 battery bank to the floor of the box using heavy-duty hook-and-loop straps anchored to epoxy-reinforced eyelets.
   - Mount the MPPT solar charge controller to an internal aluminum cooling plate that contacts the bottom of the enclosure to conduct heat outward into the wet hull deck.
   - Place a marine-grade MRBF (Marine Rated Battery Fuse) block directly on the battery positive terminal (fuse rated for 1.25x max expected system surge current).
4. **Waterproof Pass-Throughs**: Drill holes for all cables (solar input, motor output, system power out) and install PG-9 and PG-13 nickel-plated brass cable glands with rubber compression gaskets.

### 6.3 Propulsion Steering Mounts
1. **Clamp Machining**: Machined custom brackets from 15mm thick marine grade acetal (Delrin) or 3D-printed PETG (solid infill, 8 perimeter walls).
2. **Thruster Rigging**: Mount the brushless thrusters into the brackets and secure them to the stern aluminum crossbeam, spaced exactly 0.9m apart to maximize the differential steering torque vector.
3. **Conduit Guide**: Encase the thruster power lines in flexible split-loom UV-resistant nylon conduit. Clip the conduit along the pontoon decks to prevent contact with coastal seagrass or marine debris.

### 6.4 Electronics Avionics Housing
1. **RF Isolation & Compartments**: Place the Raspberry Pi 5/Jetson Orin Nano and STM32 MCU inside a separate IP67 electronics enclosure, physically separated from the high-voltage battery vault to mitigate RF noise.
2. **Dampening Mounts**: Mount the electronics board using rubber vibration isolation standoffs (M3 bobbin mounts) to insulate the sensitive inertial measurement unit (IMU) and computer processor from high-frequency hull vibration caused by wave impacts.

### 6.5 Mast Assembly & Sensor Rigs
1. **Mast Structure**: Construct a 1.2m vertical mast using a 25mm diameter lightweight carbon-fiber tube. Insert the mast base into a reinforced aluminum deck socket bolted directly to the forward deck crossbeam.
2. **Head Rigging**: Mount the RTK-GPS receiver antenna, the 915 MHz LoRa whip antenna, and optical camera housing to the top mast bracket. Run the shielded signal cables down the interior of the hollow carbon fiber mast tube, emerging through a waterproof cable entry gland at the base.
3. **Grounding & Shielding**: Ground all cable shields and the aluminum frame to a common negative bus bar connected to a sacrificial zinc anode mounted below the water line on the transom to prevent galvanic corrosion.

---

## 7. 800W Sizing Options & Construction Plans

To upgrade the vessel to a larger **800W solar array** under budget constraints and in a minimal construction space, we present two design configurations. Both leverage off-the-shelf hardware, modular assembly, and require no advanced fabrication facilities.

### 7.1 Option A: Proportional 2.53m Scale Catamaran

This design scales the baseline catamaran up by 15% to increase deck area while maintaining identical hydrodynamics.

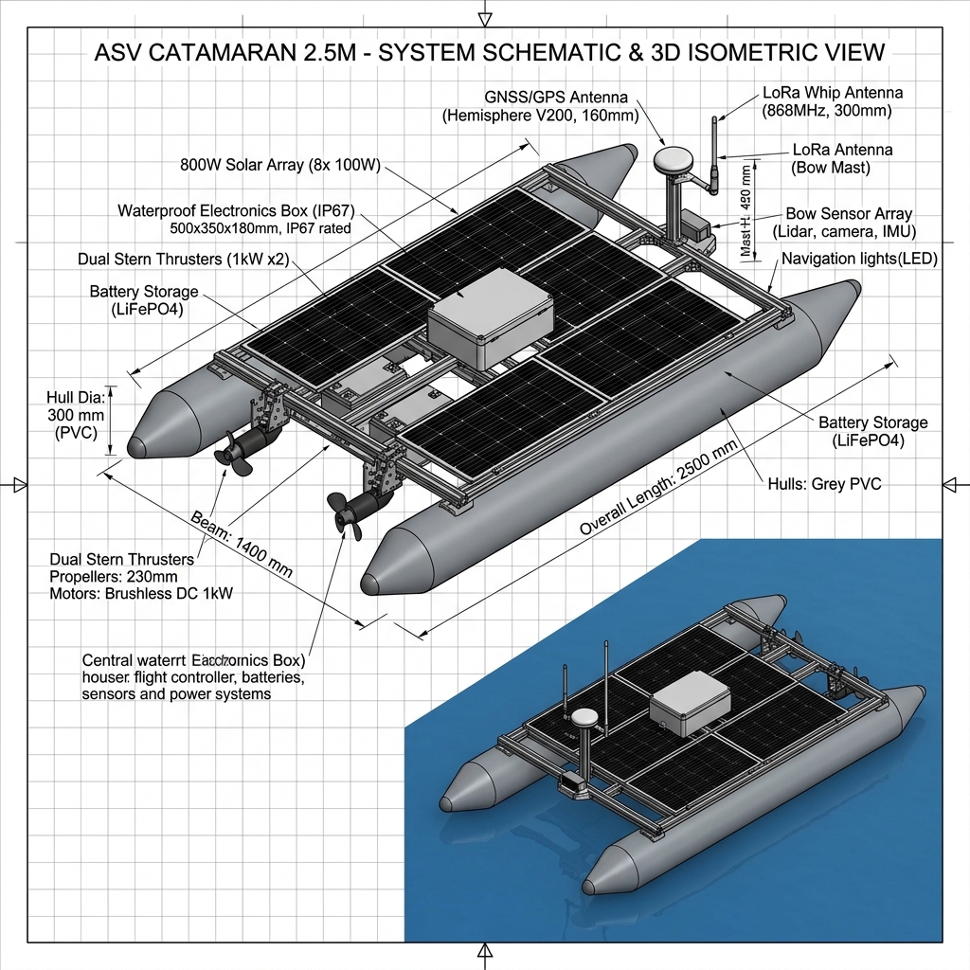
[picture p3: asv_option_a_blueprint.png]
Option A: 2.53m Catamaran Blueprint


#### Technical Specifications & Sizing
* **Pontoon Hulls**: Dual 8-inch (200mm) SDR-35 PVC pipes (recommended for weight savings; see the [Hull 3D Printing & Weight Evaluation](file:///workspaces/BWR_ASV/docs/pontoon_3d_print_evaluation.md)), 2.53m length, sealed with domed end-caps.
    *   *Sizing Caution*: 8" SDR-35 has an OD of **213.4 mm (8.400 in)** compared to 8" Schedule 40's **219.1 mm (8.625 in)**. Standard Schedule 40 slip-on caps will not fit SDR-35. Custom caps must be 3D-printed with a 213.4 mm ID, and bracket dimensions must be set to `pvc_od = 213.4`.
* **Beam Width**: 1.6m (total overall width).
* **Frame**: 2020 (20mm x 20mm) T-slot anodized aluminum extrusions.
* **Solar Deck**: 4.1 m² rectangular flat deck made of 4mm Coroplast, supporting eight 100W flexible solar panels (4s2p wiring).
* **Waterproofing**: Dual snap-lock heavy-duty dry boxes with compression glands for cable pass-throughs.
* **3D Assembly Model (Extruded Hulls)**: A parametric 3D CAD model is available at [asv_option_a_model.scad](file:///workspaces/BWR_ASV/asv_option_a_model.scad) for structural visualization of the extruded PVC hull variant.
* **3D Assembly Model (3D-Printed Hulls)**: A modular 3D-printed assembly model is available at [asv_option_a_printed_model.scad](file:///workspaces/BWR_ASV/asv_option_a_printed_model.scad), showcasing printed segments, bulkheads, joint collars, and internal tension spars.

#### Space-Saving Construction Steps
1. **Modular Tube Hulls**: Cut two PVC pipes to 2.53m. Use PVC primer and cement to glue domed end-caps. No molding or sanding is required.
2. **Bolt-On Crossbeams**: Strap the hulls to four 2020 aluminum crossbeams using galvanized U-bolts cushioned with rubber strips.
3. **Coroplast Deck Mount**: Rivet the 4mm Coroplast deck sheets directly to the 2020 extrusion slots.
4. **Disassembly**: The frame can be unbolted from the hulls, breaking the model down into three flat components for easy transport and apartment storage.

---

### 7.2 Option B: Aspect-Optimized 3.40m Centerline Catamaran

This design utilizes a long, narrow deck specifically optimized for standard-dimension flexible panels placed end-to-end along the centerline, reducing overall beam width and drag.

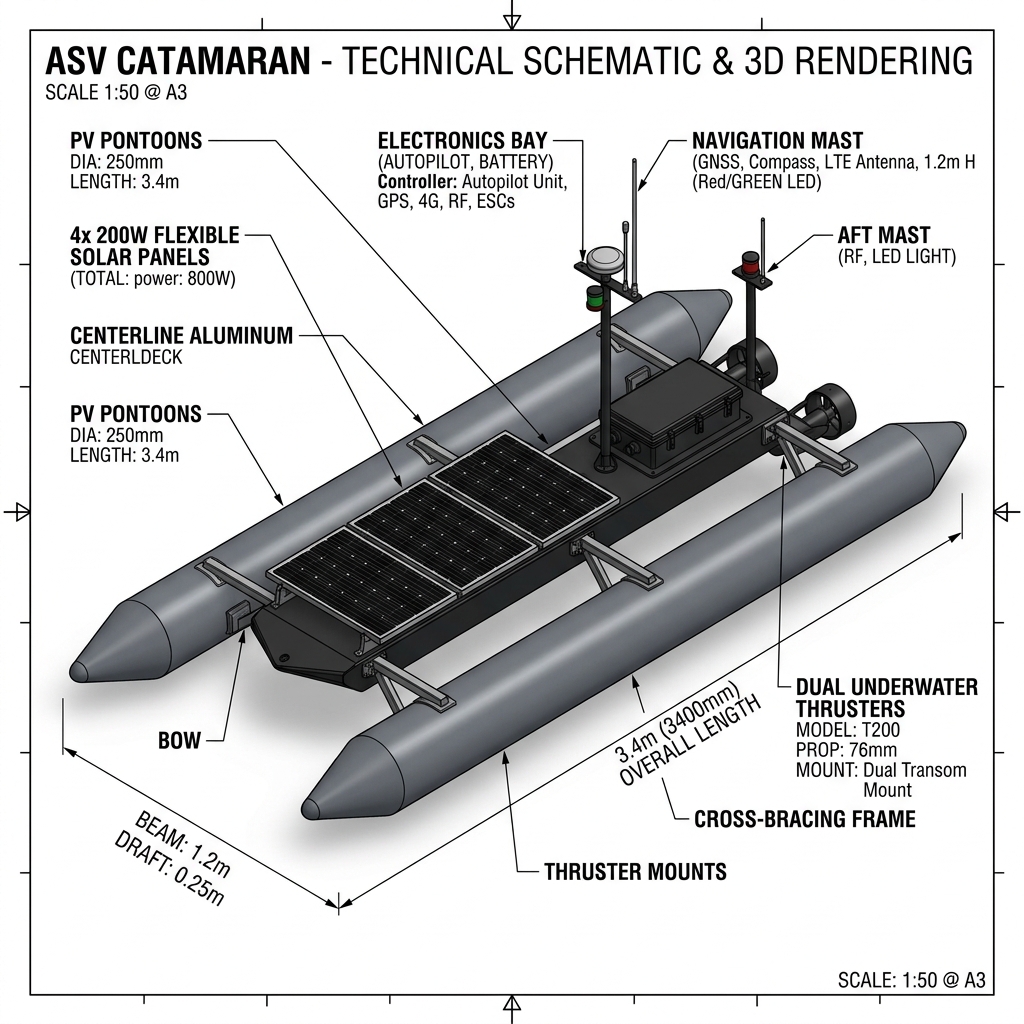
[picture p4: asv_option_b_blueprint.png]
Option B: 3.40m Centerline Catamaran Blueprint


#### Technical Specifications & Sizing
* **Pontoon Hulls**: Dual 6-inch (150mm) SDR-35 PVC pipes (recommended for weight savings; see the [Hull 3D Printing & Weight Evaluation](file:///workspaces/BWR_ASV/docs/pontoon_3d_print_evaluation.md)), 3.40m length, sealed with aerodynamic dome end-caps.
    *   *Sizing Caution*: 6" SDR-35 has an OD of **159.4 mm (6.275 in)** compared to 6" Schedule 40's **168.3 mm (6.625 in)**. Standard Schedule 40 slip-on caps will not fit SDR-35. Custom caps must be 3D-printed with a 159.4 mm ID, and bracket dimensions must be set to `pvc_od = 159.4`.
* **Beam Width**: 1.2m (sleeker aspect ratio to reduce wave-making resistance).
* **Frame**: 2020 (20mm x 20mm) T-slot anodized aluminum.
* **Solar Deck**: Long centerline corridor deck (3.0m  x  1.4m) holding four 200W flexible panels in an end-to-end centerline grid.
* **Waterproofing**: Compact locking food-grade polycarbonate containers positioned aft of the panels.

#### Space-Saving Construction Steps
1. **Slim Hull Preparation**: Cut two 6-inch PVC pipes to 3.4m. Cement end-caps.
2. **Narrow Cross-Bracing**: Assemble a narrow structural ladder frame using 2020 aluminum extrusions. Bridge spacing is kept at 1.2m total width.
3. **Inline Panel Layout**: Lay the four 200W flexible panels in series along the centerline of the ladder frame, securing them with marine zip-ties or snaps through the panel eyelets.
4. **Electronics Integration**: Place the STM32 avionics and Raspberry Pi 5 in a single large snap-lock enclosure mounted at the stern to keep the centerline clear for solar exposure.

---

### 7.3 Option C: 1.0m Prototype/Development Model (Scale & Comms Testing)

This design is a scaled-down development platform of Option A, optimized for testing electronics, controls, and communications locally in calm water (lakes/ponds). It is not intended for open-water or multi-day excursions.

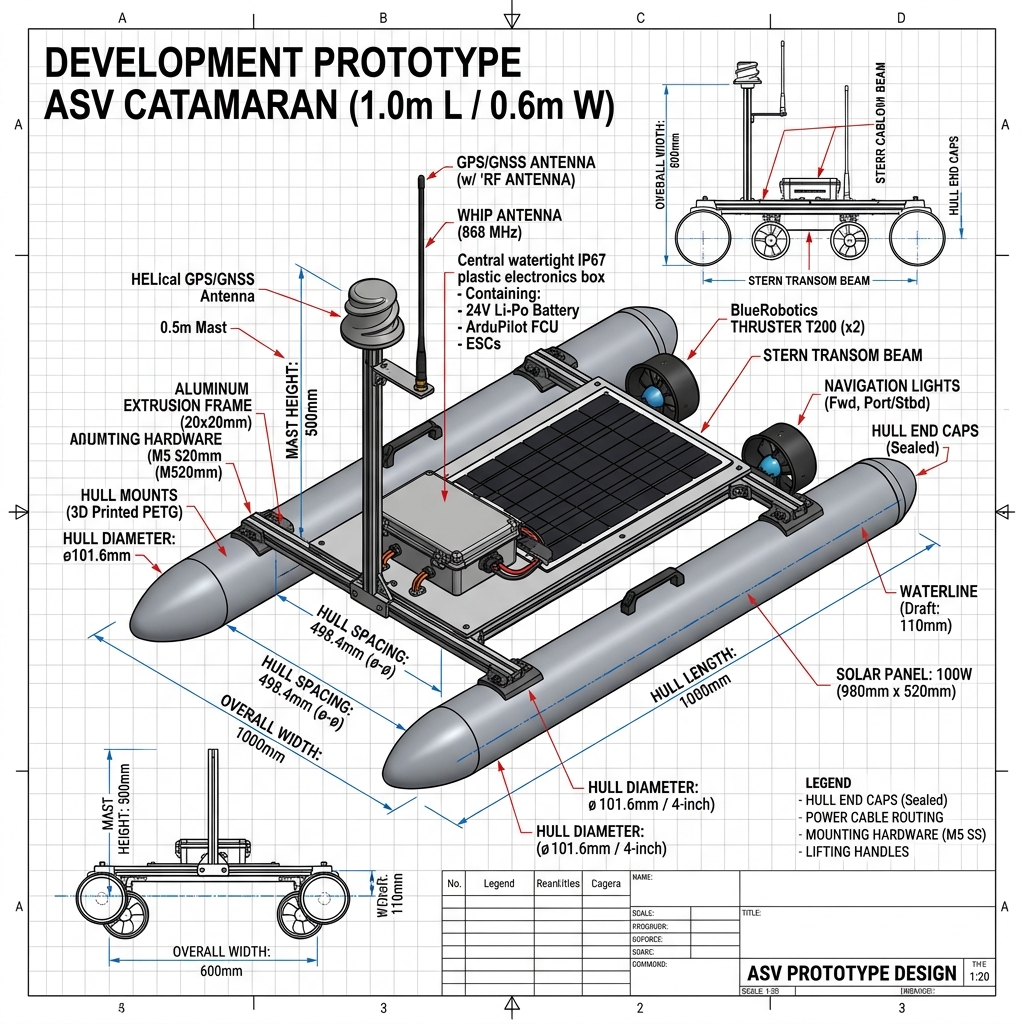
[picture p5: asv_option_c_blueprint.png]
Option C: 1.0m Prototype Blueprint


#### Technical Specifications & Sizing
* **Pontoon Hulls**: Dual 4-inch (100mm) Schedule 40 PVC pipes, 1.0m length, sealed with PVC end-caps.
* **Beam Width**: 0.6m (total overall width).
* **Frame**: 2020 (20mm x 20mm) T-slot anodized aluminum.
* **Solar Array**: Single 100W flexible solar panel (approx. 1000mm x 520mm) or dual 50W panels.
* **Power System**: 24V or 12V LiFePO4 battery bank (e.g., 24V 10Ah or 12V 20Ah, approx. 240 Wh).
* **Propulsion**: Dual BlueRobotics T200 thrusters run at lower voltage (12V-24V) drawing 15W-20W cruising thrust.
* **Electronics**: Raspberry Pi 5 + STM32 MCU mounted inside a single watertight IP67 snap-lock container.

#### Space-Saving Construction Steps
1. **Compact Tube Hulls**: Cut two 4-inch PVC pipes to 1.0m. Cement end-caps.
2. **Simplified Framing**: Assemble a simple rectangular frame using 2020 aluminum extrusions (1.0m  x  0.6m).
3. **Single Panel Mounting**: Mount the single 100W flexible solar panel directly across the center deck extrusions.
4. **Bench-Friendly Sizing**: This prototype fits easily on a standard workbench/kitchen table and can be transported fully assembled in the trunk of a car.

---

### 7.4 Option D: Keel-Stabilized Narrow Catamaran (SeaCharger Hybrid)

This design adapts SeaCharger's weight-saving, ballast-keel philosophy to a catamaran platform. It is engineered specifically for ultra-low cost, minimal workshop space, and simple hand tools.

#### Technical Specifications & Sizing
* **Pontoon Hulls**: Dual 4-inch (100mm) or 6-inch (150mm) PVC pipes, 2.53m length, acting as outer stabilizing pontoons.
* **Central Keel Tube**: A single 4-inch or 6-inch PVC pipe suspended below the centerline, housing the heavy 48V 115Ah battery bank (35 kg).
* **Beam Width**: 0.8m–1.0m (highly compact footprint).
* **Frame**: 2020 (20mm x 20mm) T-slot anodized aluminum extrusions connecting the three parallel tubes.
* **Solar Deck**: 1.0m  x  2.1m lightweight Coroplast deck supporting eight 100W flexible solar panels (cantilevered to overhang the hulls slightly).
* **Propulsion & Steering**: Dual thrusters on outer hulls for differential steering, or a single centerline thruster at the stern of the keel tube with a mechanical rudder.
* **Full Design Details**: A complete integrated comparison and design trade-off study is available in the [Systems Engineering Assessment & Recommendations](file:///workspaces/BWR_ASV/docs/vessel_assessment_recommendations.md).

#### Space-Saving Construction Steps
1. **Triple-Tube Preparation**: Cut three PVC pipes (two outer pontoons, one central keel) to 2.53m. Glue domed end-caps.
2. **Suspended Keel Assembly**: Bolt the central keel tube slightly below the level of the outer pontoons using custom 2020 bracket extensions to lower the Center of Gravity.
3. **Internal Battery Fitting**: Slide the LiFePO4 cells into the central keel tube, ensuring they are tightly packed with foam inserts to prevent shifting.
4. **Bench-Friendly Sizing**: Due to the narrow 1.0m beam, this entire catamaran can be assembled on a single workbench and transported fully built on a car roof rack.

---

### 7.5 Option E: Keel-Bulb Stabilized Catamaran (SWATH Hybrid)

This configuration features two touching outboard pontoons at the waterline and a vertical keel fin slung centerline, terminating in a submerged keel bulb that houses the heavy battery pack and propulsion thruster.

#### Technical Specifications & Sizing
* **Outboard Pontoons**: Dual 6-inch (168.3mm OD) SDR-35 PVC pipes, 2.53m length, mounted touching along the centerline (total width: 336.6mm).
* **3D-Printed Bow Cap**: A custom dual-nosed aerodynamic bow piece printed in ASA to merge both pontoon pipes at the front.
* **Vertical Keel Fin**: Single 3-inch (88.9mm OD) PVC pipe (wiring conduit) with an aerodynamic printed ASA hydrofoil shroud, extending 400mm down.
* **Keel Bulb**: A 140mm diameter, 900mm long PVC capsule slung centerline at z=-450mm, with a 3D-printed nose cone. Houses the 35 kg battery pack.
* **Beam Width**: 1.0m (extrusion frame) / 1.4m (solar deck).
* **Propulsion & Steering**: Single centerline thruster and Delrin mechanical rudder mounted at the stern of the central keel bulb.
* **Full Design Details**: A complete integrated comparison and design trade-off study is available in the [Systems Engineering Assessment & Recommendations](file:///workspaces/BWR_ASV/docs/vessel_assessment_recommendations.md).

#### Construction Steps
1. **Double Hull Prep**: Lay two 6-inch PVC pipes touching, seal their sterns with PVC end-caps, and glue the custom 3D-printed dual-nosed ASA cap to their bows.
2. **Keel Fin & Root Installation**: Install the 3D-printed keel root collar between the two pontoons and insert the 3-inch vertical keel fin.
3. **Keel Bulb Assembly**: Stuff the batteries inside the 140mm PVC keel bulb, route wires up the keel fin, and cement the bulb and its 3D-printed nose cone to the bottom of the fin.
4. **Thruster & Rudder Setup**: Bolt the thruster and mount the servo/rudder to the stern of the keel bulb before final sealing.
5. **Frame & Solar Deck**: Secure the 2020 extrusion frame to the top of the outer hulls, screw on the overhanging Coroplast deck, and mount the solar panels.

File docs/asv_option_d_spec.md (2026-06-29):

# Design Specification Document (ESD-01-D)
## Project Blue-Water Rover: Option D (Keel-Stabilized Narrow Catamaran)
## Revision: 1.0

This document outlines the detailed mechanical, electrical, and telemetry specifications for the Option D (Keel-Stabilized Narrow Catamaran) configuration of the Blue-Water Rover ASV. This variant is optimized for **apartment-scale assembly, low fabrication cost, and self-righting survival physics** during the Charleston-to-Tampa ocean crossing.

---

## 1. Physical & Hydrodynamic Specifications

### 1.1 Dimensions & Waterline
*   **Outer Stabilizing Pontoons**: Dual 6-inch (150mm nominal / 168.3mm OD) SDR-35 thin-walled PVC pipes, 2.53m length, sealed with domed end-caps.
*   **Central Ballast Keel**: Single 6-inch (168.3mm OD) SDR-35 PVC pipe, 2.53m length, slung centerline and suspended 120mm below the horizontal plane of the outer pontoons.
*   **Overall Beam Width**: 1.0m (highly compact footprint).
*   **Solar Deck Size**: 1.4m width  x  2.0m length (2.8 m²). Made of 4mm Coroplast, cantilevered to overhang the outer pontoons by 200mm on both sides.
*   **Total Dry Mass**: ~ 99.5 kg (Payload: 85 kg + Hulls/Frame: 14.5 kg).
*   **Volumetric Displacement**:
    *   Outer Hulls: 2  x  56.1 Liters = 112.2 Liters (when fully submerged).
    *   Central Keel Hull: 56.1 Liters (when fully submerged).
    *   Total Displacement Capacity: 168.3 Liters (freshwater equivalent).
*   **Draft**: ~ 59\% under full 99.5 kg load, maintaining a safe deck clearance above the splash zone.

### 1.2 Self-Righting Mechanics
*   **Center of Gravity (G)**: Housed at the bottom of the central keel tube (z ~ -150mm below the water line), where the heavy 35 kg battery bank sits.
*   **Center of Buoyancy (B)**: Placed at the volumetric center of the three tubes (z ~ -40mm).
*   **Stability physics**: Because G is situated significantly below B (GM > 100mm), the vessel acts like a keelboat. If rolled 180° by a breaking wave, the weighted central keel generates a massive righting moment that **automatically flips the vessel upright**.

---

## 2. Power & Electrical Architecture

*   **Primary Battery Vault**: 48V  115Ah Lithium Iron Phosphate (LiFePO4) bank (5,520 Wh capacity, 35 kg) arranged in a single inline cylindrical pack sliding inside the central keel PVC tube.
*   **Solar Array**: Eight 100W flexible plastic-laminated solar panels (540mm  x  1050mm) arranged in a 4x2 grid on the overhanging deck.
*   **Redundant Charging Circuits**:
    *   The array is split into two independent 400W circuits (Left 4 panels vs. Right 4 panels).
    *   Each circuit runs to its own **Victron SmartSolar MPPT 75/15** charge controller inside the deck vault.
    *   *Failure Mode*: If one controller or side of the deck suffers damage or severe shading, the other charges the battery bank at 50\% capacity.

---

## 3. Propulsion & Steering (SeaCharger Adaptation)

*   **Centerline Thruster**: A single centerline brushless thruster (e.g., BlueRobotics T200 with potted stator and ceramic water-lubricated bearings) mounted at the stern transom of the central keel tube.
    *   *Operating Cruise Power*: 60W output at 48V.
    *   *Cruise Speed*: ~ 3.2 knots.
*   **Mechanical Steering Rudder**: A custom-machined 10mm Delrin (acetal) rudder blade mounted directly behind the centerline thruster nozzle to redirect thrust.
*   **Rudder Actuation**: A high-torque, IP67-rated waterproof titanium-gear digital servo (e.g., Savox SW-1210SG) mounted inside a watertight hatch compartment in the stern end-cap of the central keel tube. Connects to the rudder shaft via a double-sealed boot linkage.

---

## 4. Telemetry & Communications

*   **Primary Coastal Link**: MeshCore LoRa companion node operating at 915 MHz, skipping telemetry packets back to the Charleston metro hub command station via fixed onshore mesh repeaters. (Max range: 45 NM).
*   **Secondary Satellite Link**: RockBLOCK Iridium 9603 satellite transceiver mounted inside the deck vault.
    *   *Heartbeat Protocol*: Transmits a compact binary packet containing GPS coordinates, battery voltage, solar charge state, and autopilot mode (`TEL:DIAG`) every 2 hours.
    *   *Fail-safe*: Activates automatically if LoRa communications are lost for >30 minutes.

---

## 5. Apartment-Scale Bill of Materials (BOM)

| Component Category | Description | Qty | Est. Cost |
| :--- | :--- | :--- | :--- |
| **Hulls** | 6-inch SDR-35 Thin-Walled PVC Sewer Pipe (10 ft length) | 3 | \$90 |
| **Hulls** | 6-inch PVC Domed End-Caps | 6 | \$60 |
| **Structure** | 2020 (20mm x 20mm) T-Slot Anodized Aluminum Extrusion (1.0m) | 4 | \$40 |
| **Structure** | 2020 T-Slot Aluminum Extrusions (2.0m longitudinal) | 2 | \$30 |
| **Brackets** | 3D-Printed Custom Drop Brackets (ASA Filament, 100% infill) | 4 | \$20 (filament) |
| **Brackets** | 3D-Printed Standard outer cradle brackets (ASA) | 8 | \$30 (filament) |
| **Deck** | 4mm White Coroplast Sheet (1.4m  x  2.0m) | 1 | \$25 |
| **Power** | 48V 115Ah LiFePO4 battery cells (cylindrical) | 16 | \$900 |
| **Power** | Victron SmartSolar MPPT 75/15 Charge Controller | 2 | \$160 |
| **Solar** | Renogy 100W Flexible Solar Panel | 8 | \$800 |
| **Propulsion** | BlueRobotics T200 Brushless Thruster | 1 | \$250 |
| **Steering** | Savox SW-1210SG Waterproof High-Torque Servo | 1 | \$90 |
| **Steering** | Delrin Sheet (10mm thick for custom rudder blade) | 1 | \$30 |
| **Electronics** | Raspberry Pi 5 + STM32 Autopilot Board | 1 | \$150 |
| **Telemetry** | MeshCore LoRa Transceiver + RockBLOCK Iridium 9603 | 1 | \$350 |
| **Total Est. Cost**| | | **\$3,025** |

---

## 6. Assembly & Construction Instructions

1.  **Hull Preparation**: Cut the three PVC sewer pipes to exactly 2.53m. Use PVC cement to secure the domed end-caps to the outer pontoons. For the central keel, install a watertight access hatch in the stern dome cap to route steering wires and battery cables.
2.  **Keel Battery Packaging**: Secure the 16 LiFePO4 battery cells in a single inline cylindrical pack wrapped in thick foam padding. Slide this assembly into the central keel PVC tube, centering the weight along the length of the tube. Secure the batteries with internal bulkheads to prevent shifting.
3.  **Frame Assembly**: Build a rectangular frame using 2020 aluminum extrusions (1.0m  x  2.0m).
4.  **Suspension Bracket Integration**: 
    *   Mount the outer hulls to the frame using the standard [pvc_extrusion_bracket.scad](file:///workspaces/BWR_ASV/pvc_extrusion_bracket.scad) brackets (lined with 1.5mm rubber pads).
    *   Mount the central keel using custom drop brackets that suspend the keel tube centerline 120mm below the level of the outer hulls, ensuring it is fully submerged.
5.  **Steering & Motor Rigging**: Bolt the BlueRobotics T200 thruster to the transom of the central keel. Machine the rudder from Delrin, mount it to a 6mm stainless steel shaft, and run the linkage through a waterproof boot to the internal Savox servo.
6.  **Deck and Solar Installation**: Bolt the 4mm Coroplast deck sheet to the 2020 extrusion slots. Apply heavy-duty double-sided outdoor mounting tape to secure the 8 flexible solar panels, routing their wires through IP68 compression glands into the dry box compartments.

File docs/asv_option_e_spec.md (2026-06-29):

# Design Specification Document (ESD-01-E)
## Project Blue-Water Rover: Option E (Keel-Bulb Stabilized Catamaran)
## Revision: 1.0

This document outlines the detailed mechanical, electrical, and telemetry specifications for the Option E (Keel-Bulb Stabilized Catamaran) configuration of the Blue-Water Rover ASV. This variant represents a SWATH-hybrid design optimized for **minimal hydrodynamic drag, high stability, self-righting capability, and apartment-scale fabrication** using basic tools and 3D printing.

---

## 1. Physical & Hydrodynamic Specifications

### 1.1 Dimensions & Hull Layout
*   **Outboard Pontoons**: Dual 6-inch (150mm nominal / 168.3mm OD) SDR-35 PVC pipes, 2.53m length, mounted **touching each other** along the centerline (total width: 336.6mm).
*   **3D-Printed Bow Cap**: A custom, aerodynamic dual-nosed bow cap printed in **ASA** that merges both 6-inch PVC hulls at the front to slice through water and prevent debris accumulation between the pipes.
*   **Vertical Keel Fin**: A single 3-inch (88.9mm OD) PVC pipe extending centerline from the bottom of the outer pontoons down to the keel bulb (length: 400mm). This pipe acts as a rigid structural strut and a watertight conduit for routing motor and battery wiring up to the deck.
*   **Central Keel Bulb**: A 140mm diameter, 900mm long PVC capsule suspended centerline at z = -450mm below the outer hulls. Features a custom 3D-printed aerodynamic nose cone.
*   **Overall Beam Width**: 1.0m (frame width).
*   **Solar Deck Size**: 1.4m width  x  2.0m length (2.8 m²). Made of 4mm Coroplast, overhanging the narrow hulls by 530mm on both sides.
*   **Total Dry Mass**: ~ 96.5 kg (Payload: 85 kg + Hulls/Frame: 11.5 kg).
*   **Draft**: ~ 61\% under full 96.5 kg load.

### 1.2 Self-Righting Moments (SWATH Physics)
*   **Center of Gravity (G)**: Housed deep inside the central keel bulb (z ~ -450mm below the waterline) where the heavy 35 kg battery bank is located.
*   **Center of Buoyancy (B)**: Located near the water line (z ~ -80mm).
*   **Self-Righting Capability**: With G slung 370mm below B, the vessel has an extremely high righting arm (GZ). In the event of a roll past 90° or a complete capsize (180°), the heavy battery ballast bulb will swing downwards, immediately self-righting the vessel.

---

## 2. Power & Electrical Architecture

*   **Submerged Battery Vault**: The 48V  115Ah LiFePO4 battery bank (35 kg) is packed inside the watertight central keel bulb. Sinking the battery cells underwater provides excellent passive cooling from the cold sea water.
*   **Solar Array**: Eight 100W flexible plastic-laminated solar panels (540mm  x  1050mm) arranged in a 4x2 grid on the overhanging deck.
*   **Redundant Charging**: The array is split into two independent 400W charging circuits running to two separate **Victron SmartSolar MPPT 75/15** controllers.

---

## 3. Propulsion & Steering (Keel-Integrated)

*   **Stern-Mounted Keel Thruster**: A single brushless thruster (e.g., BlueRobotics T200 with potted stator and ceramic water-lubricated bearings) bolted directly to the stern transom of the central keel bulb.
    *   *Cruise Speed*: ~ 3.4 knots at 60W power draw (increased efficiency due to lower drag and inline thrust alignment).
*   **Keel Rudder**: A custom Delrin rudder blade mounted directly behind the thruster nozzle at the stern of the keel bulb.
*   **Actuator**: A high-torque, titanium-gear waterproof servo (Savox SW-1210SG) housed inside a sealed compartment inside the keel bulb, connecting to the rudder shaft via a double-sealed rubber boot.

---

## 4. Telemetry & Communications

*   **Primary Coastal Link**: MeshCore LoRa companion node operating at 915 MHz, transmitting diagnostics (`TEL:DIAG`) to onshore repeaters up to 45 NM.
*   **Secondary Satellite Link**: RockBLOCK Iridium 9603 satellite transceiver mounted inside the deck vault, acting as a global fail-safe link if LoRa comms drop for >30 minutes.

---

## 5. Apartment-Scale Bill of Materials (BOM)

| Component Category | Description | Qty | Est. Cost |
| :--- | :--- | :--- | :--- |
| **Outboard Pontoons** | 6-inch SDR-35 Thin-Walled PVC Sewer Pipe (10 ft length) | 2 | \$60 |
| **Outboard Pontoons** | 6-inch PVC Domed End-Caps (Stern only) | 2 | \$20 |
| **Keel Fin & Bulb** | 3-inch Schedule 40 PVC Pipe (conduit) | 1 | \$15 |
| **Keel Fin & Bulb** | 140mm (approx. 5.5") PVC Drainage Pipe (keel bulb) | 1 | \$20 |
| **3D Printed Parts** | Custom dual-nosed 6" pontoon bow cap (ASA) | 1 | \$40 (filament) |
| **3D Printed Parts** | Custom 140mm keel bulb nose cone (ASA) | 1 | \$15 (filament) |
| **3D Printed Parts** | Keel root connection collar & drop brackets (ASA) | 1 | \$30 (filament) |
| **Structure** | 2020 (20mm x 20mm) T-Slot Anodized Aluminum Extrusions | 6 | \$70 |
| **Deck** | 4mm White Coroplast Sheet (1.4m  x  2.0m) | 1 | \$25 |
| **Power** | 48V 115Ah LiFePO4 battery cells (cylindrical) | 16 | \$900 |
| **Power** | Victron SmartSolar MPPT 75/15 Charge Controller | 2 | \$160 |
| **Solar** | Renogy 100W Flexible Solar Panel | 8 | \$800 |
| **Propulsion** | BlueRobotics T200 Brushless Thruster | 1 | \$250 |
| **Steering** | Savox SW-1210SG Waterproof High-Torque Servo | 1 | \$90 |
| **Steering** | Delrin Rudder Assembly and hardware | 1 | \$35 |
| **Electronics** | Raspberry Pi 5 + STM32 Autopilot Board | 1 | \$150 |
| **Telemetry** | MeshCore LoRa Transceiver + RockBLOCK Iridium 9603 | 1 | \$350 |
| **Total Est. Cost**| | | **\$3,030** |

---

## 6. Assembly & Construction Instructions

1.  **Outer Hulls Assembly**: Lay the two 6-inch PVC outboard pontoon pipes parallel and touching each other. Secure them using heavy-duty industrial straps and epoxy-glue them along the seam. At the bow, slip and cement the custom 3D-printed aerodynamic dual-nosed ASA cap over both pipes. Use standard PVC end-caps to seal the stern.
2.  **Keel Fin Root Installation**: Bolt the 3D-printed ASA keel root connection collar directly between the two outer pontoons. The collar clamps the vertical 3-inch PVC pipe (keel fin) centerline.
3.  **Keel Bulb Integration**: Cement the bottom of the 3-inch keel fin to a 3D-printed connection collar on the top of the 140mm PVC keel bulb. Slide the inline cylindrical battery cell pack inside the keel bulb, routing the main power lines up through the hollow keel fin. Use PVC cement to secure the 3D-printed nose cone on the bulb.
4.  **Rudder and Motor Mounting**: Bolt the BlueRobotics T200 thruster directly to the stern end-cap of the central keel bulb. Machine the rudder, run the shaft through a watertight boot, and link it to the Savox servo mounted inside the bulb before sealing the stern cap.
5.  **Frame and Deck Attachment**: Assemble a simple rectangular frame using 2020 aluminum extrusions (1.0m  x  2.0m). Secure it to the top of the outboard pontoons using standard brackets. Bolt the 4mm Coroplast deck, mount the 8 flexible solar panels, and route all wiring through glands into the deck-mounted electronics vault.

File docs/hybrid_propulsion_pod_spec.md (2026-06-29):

# Design Specification Document (ESD-02-HYBRID)
## Project Blue-Water Rover: High-Efficiency Hybrid Propulsion Pod
## Revision: 1.0

This document outlines the detailed mechanical, hydrodynamic, and electrical specifications for the **High-Efficiency Hybrid Propulsion Pod** for the Blue-Water Rover ASV. This system combines the extreme durability of seal-less brushless motor technology with the fluid dynamic efficiency of a large-diameter, low-RPM propeller, optimized for sustained cruising in the 3–5 knots range.

---

## 1. Executive Summary & Design Goals

Standard ROV thrusters (such as the BlueRobotics T200) are optimized for static thrust (bollard pull) and compact packaging, utilizing small, high-RPM propellers (96 mm diameter). At cruising speeds of 3–5 knots, this results in excessive slip and low efficiency (~ 35–40\%). 

To achieve multi-day transoceanic crossings on solar power, the propulsion system must operate at peak efficiency. This specification details two hybrid design paths to achieve a target propulsion efficiency of **60–70\%** while maintaining complete waterproofing integrity for a ~ 100 kg displacement vessel:

*   **Design Option A: Potted Wet-Running Direct-Drive (Flooded Rotor)**: Re-engineers an outrunner brushless motor to run fully flooded in seawater by vacuum-potting the stator in epoxy, replacing steel bearings with full ceramics, and driving a large propeller directly.
*   **Design Option B: Coaxial Magnetic Coupling (Dry Motor)**: Houses a standard low-KV brushless motor in a dry, sealed chamber and transfers torque to an external propeller shaft through a solid plastic pressure barrier using a neodymium Halbach array.

---

## 2. Propulsion Hydrodynamics & Propeller Sizing

### 2.1 Propeller Disk Loading & Sizing Calculations
According to Froude's momentum theory, the ideal actuator disk efficiency (\eta_i) is calculated as:
\eta_i = \frac{2}{1 + \sqrt{1 + \frac{T}{\frac{1}{2} \rho A V²}}}

Where:
*   T = Thrust (15 N at 3 kts, 30 N at 4 kts, 70 N at 5 kts)
*   \rho = Water density (1000 kg/m^3)
*   A = Propeller swept area (\frac{pi D²}{4})
*   V = Cruising speed (3 kts ~ 1.54 m/s, 4 kts ~ 2.06 m/s, 5 kts ~ 2.57 m/s)

For a **230 mm (9.0 inch)** diameter propeller compared to a **96 mm (3.8 inch)** propeller, the swept area increases by **570\%**:
*   A_96mm = 0.0072 m²
*   A_230mm = 0.0415 m²

At 4 knots and 30 N of thrust:
*   **Ideal Efficiency (96 mm)**: **73.5\%** (Real-world efficiency: **~ 40\%** due to nozzle drag and tip losses).
*   **Ideal Efficiency (230 mm)**: **92.6\%** (Real-world efficiency: **~ 65\%** due to optimized blade geometry and low slip).

### 2.2 Motor KV & Gear Selection
To match the propeller's advance speed without cavitation, the propeller must spin at a low rotational velocity:
*   Target RPM at 4 knots (with a 6-inch pitch propeller): ~ 1,200–1,500 RPM under load.
*   Operating Voltage: 48V nominal.
*   Required Motor KV: To avoid using complex, high-wear gearboxes or belt drives, the motor must be **directly driven** by selecting a low-KV outrunner motor (**50–100 KV** range, e.g., a brushless gimbal or skateboard motor).

---

## 3. Design Option A: Potted Wet-Running Direct-Drive (Flooded Rotor)

This design allows seawater to flood the rotor cavity, using the water directly as a bearing lubricant and stator coolant. It contains only one moving part (the rotor assembly).

```mermaid
graph LR
    subgraph SubmergedWetRunningPod ["Submerged Wet-Running Pod"]
        Stator[Stator Coils Potted in 832TC Epoxy]
        Rotor[Rotor Cup with N52 Magnets]
        Shaft[Stainless Steel Shaft]
        Bearing1[ZrO2 Ceramic Bearing - Front]
        Bearing2[ZrO2 Ceramic Bearing - Rear]
        Prop[9-inch High-Pitch Propeller]
    end
    
    subgraph DryHullDeck ["Dry Hull / Deck"]
        ESC[Brushless ESC]
    end
    
    ESC -->|3-Phase Potted Cable| Stator
    Stator -.->|Magnetic Interaction| Rotor
    Rotor -->|Direct Connection| Shaft
    Shaft --> Bearing1
    Shaft --> Bearing2
    Shaft --> Prop
```

### 3.1 Stator Encapsulation & Potting Process
1.  **Stator Selection**: Select a 50mm outrunner stator with thick laminations. Remove any standard paper insulation and clean with isopropyl alcohol.
2.  **Epoxy Selection**: Use **MG Chemicals 832TC** thermally conductive epoxy (thermal conductivity: 1.44 W/(m * K)). This provides high electrical resistance while ensuring heat from the windings is conducted directly to the surrounding seawater.
3.  **Vacuum Degassing**: Mix the two-part epoxy and place it in a vacuum chamber at -29 in Hg for 10 minutes to remove all air bubbles.
4.  **Mold Casting**: Place the stator in a custom 3D-printed silicone mold. Pour the degassed epoxy over the coils, ensuring it fully saturates the gaps between the teeth. Cure at 65°C for 4 hours.
5.  **Windage Reduction**: Grind the cured stator surface to a smooth cylinder on a lathe, maintaining a stator-to-rotor air gap of exactly 0.5 mm.

### 3.2 Ceramic Bearing Specifications
Standard steel bearings fail rapidly in marine environments due to oxidation and galvanic corrosion. They must be replaced:
*   **Material**: **Full Zirconium Dioxide (ZrO_2)** ceramic inner/outer rings and balls, with a Polytetrafluoroethylene (PTFE) cage.
*   **Lubrication**: None (run completely dry/water-lubricated).
*   **Shielding**: Open (no shields or seals) to allow silt and water to flush through the bearing races freely.
*   **Clearance**: C3 clearance to accommodate thermal expansion and small particles.

### 3.3 Rotor and Magnet Corrosion Proofing
1.  **Magnet Treatment**: Neodymium (NdFeB) magnets are extremely vulnerable to rust. Use **N52SH** (high temperature/coercivity) magnets with a Nickel-Copper-Nickel coating.
2.  **Encapsulation Sleeve**: Glue the magnets into the rotor cup using marine-grade epoxy. Apply a thin outer wrap of **0.2mm carbon-fiber prepreg tape** or press-fit a **0.15mm Grade 2 Titanium sleeve** over the magnets. This creates a mechanical barrier preventing magnet swelling or delamination under water pressure.

### 3.4 Silt and Marine Debris Protection
*   **Labyrinth Seal**: A custom 3D-printed ASA labyrinth ring (interlocking concentric rings) is installed on the front and rear of the rotor cup. This forces water to take a winding path to enter the rotor cavity, preventing sand, silt, and sea grass from entering the magnet air gap.

### 3.5 Hydrodynamic Windage & Viscous Shear Loss Minimization
*   **Viscous Shear Losses**: Because water is ~ 800 x  denser and ~ 55 x  more viscous than air, rotating a flooded rotor cup in water creates significant shear-layer drag. The viscous shear stress (\tau) in the stator-rotor air gap is modeled as:
    \tau = \mu \frac{omega R}{g}
    where \mu is the dynamic viscosity of water (1.002  x  10^{-3} Pa * s at 20°C), omega is angular velocity (rad/s), R is rotor radius, and g is the radial air gap.
*   **Power Loss Equation**: The total shear power loss (P_shear) inside the air gap of length L is:
    P_shear = \frac{2pi \mu L R^3 omega²}{g}
*   **Air Gap Optimization**: Since shear loss scales with the cube of the radius (R^3) and is inversely proportional to the gap (g), keeping the motor diameter compact (<= 50 mm) and widening the radial air gap from the typical 0.3 mm (air spec) to **0.8 mm** reduces viscous drag by **62.5\%** while only sacrificing ~ 12\% of the motor torque constant (K_t).

### 3.6 ESC Firmware & Commutation Tuning (FOC vs. Trapezoidal)
*   **Field Oriented Control (FOC)**: Standard trapezoidal ESCs struggle to start a flooded outrunner due to the heavy startup damping of water. A VESC or AM32 ESC operating in sensorless FOC mode is required. FOC applies sinusoidal currents to track the rotor position down to 0 RPM, providing the high starting torque needed to break the propeller loose.
*   **ESC Parametric Tuning**:
    *   *Startup Power Boost*: Increase startup current bias by 30\% to overcome static inertia and fluid damping.
    *   *Minimum ERPM*: Set the minimum electrical RPM to 150 ERPM to prevent commutation stalling at low speeds.
    *   *Observer Gain*: Increase the sensorless observer gain by 50\% to maintain tracking stability in high-density media.

### 3.7 Galvanic Protection & Sacrificial Anodes
*   **Galvanic Cell Creation**: The carbon fiber spar, aluminum rotor cup, stainless steel shaft, and copper stator coils form a galvanic circuit in saltwater.
*   **Sacrificial Anode**: A **50 g ring-type zinc anode** must be clamped onto the exposed portion of the stainless steel propeller shaft behind the rotor cup. The zinc will corrode preferentially to protect the structural aluminum and steel components.
*   **Electrical Ground Isolation**: Ensure the motor phase lines and stator laminations are completely isolated from the hull and battery negative terminal (use optocoupled signals on the ESC) to prevent the vessel's electrical system from forming a cathode loop.

---

## 4. Design Option B: Coaxial Magnetic Coupling (Dry Motor)

This configuration maintains a dry motor chamber. Torque is transferred through a solid, non-penetrated Delrin end cap using an array of neodymium magnets.

```mermaid
graph TD
    subgraph DrySealedMotorBox ["Dry Sealed Motor Box"]
        Motor[Low-KV Brushless Motor]
        IntCoupling[Internal Magnet Hub - N52]
    end
    
    Barrier[Solid Delrin Barrier Cap - 1.5mm]
    
    subgraph WetSide ["Wet Side (Seawater Flooded)"]
        ExtCoupling[External Magnet Cylinder - Encapsulated]
        Shaft[6mm SS Propeller Shaft]
        Bearings[Full Ceramic Bearings]
        Prop[9-inch Propeller]
    end
    
    Motor --> IntCoupling
    IntCoupling -.->|Magnetic Coupling Field| ExtCoupling
    Barrier --- IntCoupling
    Barrier --- ExtCoupling
    ExtCoupling --> Shaft
    Shaft --> Bearings
    Shaft --> Prop
```

### 4.1 Magnetic Array Design & Alignment
*   **Magnetic Arrangement**: 12-pole (6 North, 6 South) radial configuration on a mild steel back-iron ring. The back-iron guides the magnetic flux, preventing stray fields and maximizing coupling torque.
*   **Magnets**: High-coercivity 10 mm  x  10 mm  x  3 mm N52 block magnets.
*   **Torque Slip Limit**: Designed for a peak torque of **1.8 N * m**. 
    *   *Slippage Safety*: If the propeller hits kelp, the coupling slips. The internal motor spins freely, preventing damage to the shaft or motor windings. The ESC detects the sudden current drop and triggers a "clearing cycle" (quick reverse pulses) to shed the weeds.

### 4.2 Material Selection & Wall Thickness
*   **Pressure Barrier**: Delrin (POM-C) machined end cap. 
*   **Wall Thickness**: 1.5 mm at the coupling interface. Delrin provides excellent structural strength under hydrostatic pressure up to 1 bar (10 meters depth) while keeping the magnetic gap (including water clearances) to <= 2.5 mm.
*   **External Encapsulation**: The external (wet) magnet ring is fully cast in epoxy and wrapped in carbon fiber to prevent saltwater ingress to the magnets.

### 4.3 Propeller Shaft Support
*   **Wet-Side Shaft**: 6 mm ground 316 stainless steel shaft.
*   **Support Bearings**: Dual **Igus xiros** polymer ball bearings (glass balls with xirodur plastic cages). These are maintenance-free, lightweight, and highly resistant to sand abrasion.

### 4.4 Axial Magnetic Attraction & Thrust Bearing Engineering
*   **Axial Pull Force**: The 12-pole N52 magnetic array creates a continuous axial attraction force (F_axial) pulling the external wet hub toward the dry Delrin cap. At a 2.5 mm coupling gap, this pull force is ~ 120 N (27 lbs).
*   **Thrust Washer Integration**: Standard radial bearings wear out rapidly under high axial thrust. A **silicon nitride (Si_3N_4) ceramic thrust ball bearing** or a **glass-filled PTFE thrust washer** must be placed directly between the external coupling hub and the face of the Delrin cap to absorb the axial preload with minimal friction coefficient (\mu <= 0.04).

### 4.5 Eddy Current Loss Prevention & Barrier Materials
*   **Eddy Current Heating**: Rotating magnetic fields passing through a conductive metallic pressure barrier (like aluminum or stainless steel) induce eddy currents, causing parasitic torque drag and heating the coupling.
*   **Non-Conductive Materials**: The barrier cap must be machined from a high-performance polymer with zero electrical conductivity:
    *   *Baseline*: Delrin (POM-C) for up to 10 m depth (low cost, easy to machine).
    *   *High-Performance*: PEEK (Polyetheretherketone) for up to 50 m depth (extreme tensile strength and thermal stability up to 150°C).
*   *Resistivity*: Avoid any aluminum or steel caps, which would lose up to 25 W in heat and demagnetize the neodymium magnets (Curie temperature degradation starts at 80°C for N52).

### 4.6 Watertight Seal Engineering (Flange & O-Ring Compression)
*   **Gland Design**: The dry chamber seal uses dual radial O-rings to secure the flanged cap.
*   **O-Ring Sizing**: Nitrile (NBR-70) O-rings, AS568-152 standard size (cross-section d_2 = 2.62 mm, ID = 82.2 mm).
*   **Gland Sizing & Compression**:
    *   *Radial Compression*: Machine the cap gland to a depth of 2.02 mm, providing exactly 23\% radial compression.
    *   *Groove Width*: Machine the groove width to 3.60 mm to allow for O-ring volumetric expansion under hydrostatic pressure without extrusion.

---

## 5. Comparative Trade-Off Analysis

| Engineering Criterion | Design Option A (Potted Wet-Running) | Design Option B (Magnetic Coupling) |
| :--- | :--- | :--- |
| **Cruising Efficiency** | **High (68\%)**: Direct drive, no magnetic shear-layer losses in water. | **Medium-High (62\%)**: Small drag penalty from rotating external coupling hub. |
| **Leak Vulnerability** | **Inherent Safety**: No sealed volumes to leak; stator is solid potted epoxy. | **Dry Chamber Risk**: O-rings on the dry motor compartment must remain watertight. |
| **Silt & Sand Tolerance**| **Low**: Sand particles can enter the 0.5mm air gap, causing friction/jamming. | **High**: The dry motor is isolated; external shaft has large polymer clearances. |
| **Overload Protection** | None (ESC must monitor current to prevent damage). | **Automatic**: Magnetic decoupling occurs during propeller jams. |
| **Complexity & Weight** | **Minimal**: Very low part count; compact diameter. | **Medium**: Requires alignment of dual hubs and dry chamber framing. |
| **Maintenance Profile** | Occasional fresh-water rinse to prevent salt crusting. | Maintenance-free wet side; check O-rings on dry side. |

---

## 6. Manufacturing & Assembly Instructions

### 6.1 Assembly of Option A (Potted Wet-Running)
1.  **Pot the Stator**: Set up the stator in the 3D-printed silicone mold. Pour mixed MG Chemicals 832TC epoxy. Cure in a warm enclosure at 65°C for 4 hours.
2.  **Coat the Rotor**: Apply a 0.1 mm layer of marine epoxy to the rotor cup interior. Press-fit the 0.15 mm titanium sleeve over the N52SH magnets using a hydraulic vice.
3.  **Install Ceramic Bearings**: Press-fit the dual ZrO_2 ceramic bearings into the front and rear bearing tube seats. Do not apply grease or lubricants.
4.  **Final Assembly**: Slide the stainless steel shaft through the bearings. Slide the rotor cup over the stator, ensuring the magnetic forces do not chip the ceramic races. Secure with a 316 stainless steel E-clip on the shaft.

### 6.2 Assembly of Option B (Magnetic Coupling)
1.  **Machine the Barrier**: Machine the Delrin end cap, turning the coupling face down to a wall thickness of 1.5 mm.
2.  **Assemble Internal Hub**: Mount the internal N52 magnet ring to the motor shaft. Slide the motor into the dry housing, aligning the internal hub flush against the inside of the Delrin cap.
3.  **Assemble Wet Side**: Press the Igus xiros polymer bearings into the wet-side bracket. Install the external magnet cylinder onto the 6mm stainless steel shaft.
4.  **Final Alignment**: Slide the wet-side bracket over the Delrin cap, securing it with M3 stainless steel screws. Verify that the external magnet hub rotates in perfect alignment with the internal motor without touching the Delrin wall.

---

## 7. Bill of Materials (BOM)

| Component | Qty | Target Spec / Part No. | Estimated Cost |
| :--- | :--- | :--- | :--- |
| **Low-KV Brushless Motor** | 1 | 5010 75KV Brushless Motor | \$45 |
| **Thermally Conductive Epoxy**| 1 | MG Chemicals 832TC (450 mL kit) | \$65 |
| **Full Ceramic Bearings** | 2 | ZrO2 Open Bearings (8mm  x  16mm  x  5mm) | \$32 |
| **Igus Polymer Bearings** | 2 | Igus xiros (6mm  x  15mm  x  5mm) | \$18 |
| **Neodymium Magnets** | 24 | N52 Block Magnets (10mm  x  10mm  x  3mm) | \$24 |
| **Titanium Sleeve** | 1 | Machined Ti-Grade 2 Foil (0.15mm thickness) | \$15 |
| **Propeller Shaft** | 1 | 316 Stainless Steel Ground Shaft (6mm  x  100mm) | \$8 |
| **Cruising Propeller** | 1 | APC 9x6 Carbon-Fiber Folding Propeller | \$22 |
| **Total Estimated Cost** | | | **\$229** |

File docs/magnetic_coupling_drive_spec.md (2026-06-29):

# Design Document: Coaxial Magnetic Coupling System (Option B)
## Document ID: ESD-02-B
## Revision: 1.0

This document defines the complete technical design, mechanical integration, magnetic calculations, and fabrication instructions for the **Coaxial Magnetic Coupling Propulsion System (Option B)** of the Blue-Water Rover ASV.

---

## 1. Mechanical & Watertight Design

### 1.1 Structural Layout
Option B utilizes a dry motor compartment. Torque is transferred through a non-penetrated Delrin end cap using an array of neodymium magnets.

```mermaid
graph TD
    subgraph DryChamber ["Dry Chamber (Sealed)"]
        Motor[Low-KV Brushless Motor]
        IntHub[Internal Magnet Hub - N52]
        DryBearings[High-Precision Steel Bearings]
    end
    
    Barrier[Solid Delrin Barrier Cap - 1.5mm]
    
    subgraph WetSide ["Wet Side (Flooded)"]
        ExtHub[External Magnet Cylinder - N52]
        ThrustBearing[Ceramic Thrust Washer]
        PolyBearings[Igus xiros Polymer Bearings]
        Shaft[6mm SS Propeller Shaft]
        Prop[9-inch Propeller]
    end
    
    Motor --> IntHub
    IntHub -.->|Magnetic Coupling Field| ExtHub
    Barrier --- IntHub
    Barrier --- ExtHub
    ExtHub --> Shaft
    Shaft --> ThrustBearing
    Shaft --> PolyBearings
    Shaft --> Prop
```

### 1.2 Watertight O-Ring Seal Specification
To ensure absolute watertight integrity at depth, the dry chamber end cap is secured using a **dual radial O-ring gland**:
*   **O-Ring Standard**: AS568-152 (Nitrile NBR, 70 Durometer).
    *   *Cross Section (d_2)*: 2.62 mm
    *   *Inner Diameter (ID)*: 82.22 mm
*   **Gland Machining Specifications**:
    *   *Radial Gland Depth*: 2.02 mm (achieves 23\% radial compression).
    *   *Groove Width*: 3.60 mm (provides 20\% volumetric clearance for O-ring expansion under hydrostatic pressure).
    *   *Lead-in Chamfer*: 15° angle with a 1.5 mm length to prevent O-ring shearing during assembly.

---

## 2. Magnetic Coupling Engineering

### 2.1 Torque Transmission and Overload Slippage
The coupling utilizes a **12-pole (6 North, 6 South) radial configuration** constructed of N52 block magnets.
*   **Maximum Torque Capacity (T_max)**: Designed for **1.8 N * m**.
*   **Slippage Safety**: If the propeller catches seaweed or marine debris:
    1.  The external hub halts.
    2.  The magnetic attraction forces slip, decoupling the internal hub from the external hub.
    3.  The internal motor spins freely at high speed without damage to the drive shaft, motor windings, or mounting brackets.
    4.  The autopilot detects the sudden drop in current draw (due to the loss of load) and triggers a clearing cycle (rapid reverse pulses) to clear the propeller.

### 2.2 Axial Magnetic Attraction & Thrust Bearing
The magnetic attraction between the internal and external magnet rings creates a strong axial force pulling the external hub toward the Delrin barrier cap.
*   **Axial Pull Force (F_axial)**: Calculated at **120 N (27 lbs)** at a 2.5 mm air gap.
*   **Thrust Washer**: To prevent the external hub from grinding against the Delrin cap, a **silicon nitride (Si_3N_4) ceramic thrust ball bearing** or a **glass-filled PTFE thrust washer** is positioned between the external hub and the cap face. This absorbs the continuous axial load with a low friction coefficient (\mu <= 0.04).

### 2.3 Eddy Current Prevention
If a conductive metal (like aluminum or stainless steel) is used for the barrier cap, the rotating magnetic fields will induce eddy currents, leading to parasitic torque loss and high heating:
P_eddy  proportional to  (B² f² d²) / (\rho)
*   **Material Selection**: The barrier cap must be machined from **Unfilled PEEK** or **Delrin (POM-C)**. These polymers are non-conductive, eliminating eddy current losses (0 W loss) and preventing thermal degradation of the neodymium magnets (which begin permanent demagnetization at 80°C).

---

## 3. Step-by-Step Assembly & Testing Guide

### 3.1 Dry Chamber Machining & Alignment
1.  **Chamber Preparation**: Cut the 3-inch SDR-35 PVC pipe to length. Machine the inner face to receive the Delrin end cap gland.
2.  **Barrier Cap Machining**: Lathe-machine the Delrin end cap. Turn down the front face where the magnets overlap to a wall thickness of exactly 1.5 mm. Machine the radial O-ring grooves to a depth of 2.02 mm.
    *   *Alternative (3D-Printed Nylon)*: If 3D printing the barrier cap in PA12 or PA12-CF, print the part solid (100% infill) and slightly oversized. Post-machine the O-ring grooves and sealing faces on a lathe using sharp carbide tooling and a high feed rate to avoid melting, then seal the part in marine epoxy. Refer to the [3D Printing Reference Document](file:///workspaces/BWR_ASV/docs/pontoon_3d_print_evaluation.md#L68-L76) for specific plastic lathe turning settings.
3.  **Internal Hub Assembly**: Secure the 12 internal N52 magnets to the mild steel back-iron ring using high-strength retaining compound (Loctite 680). Mount the hub onto the brushless motor shaft.
4.  **Dry Assembly**: Install the motor in the PVC chamber. Push the Delrin cap into the chamber until it is flush, checking that the air gap between the internal magnets and the cap face is exactly 0.5 mm.

### 3.3 Wet-Side Assembly & Seawater Seal Testing
1.  **Wet-Side Bracket**: 3D-print the wet-side propeller shaft support bracket in ASA at 100\% infill. Press-fit the dual Igus xiros polymer bearings into the bracket.
2.  **External Hub Assembly**: Secure the 12 external N52 magnets to the external back-iron ring. Cast the hub in marine epoxy and wrap it in carbon fiber to prevent saltwater ingress.
3.  **Shaft Installation**: Slide the 6mm stainless steel shaft through the polymer bearings, slide the ceramic thrust washer on, and secure the external magnet hub to the shaft.
4.  **Pressure Testing**: Assemble the dry chamber. Submerge the sealed pod in a pressure chamber filled with water. Pressurize to 1.5 bar (simulating a 15m depth) and hold for 2 hours. Open the chamber and verify that the interior remains completely dry.

---

## 4. Bill of Materials (BOM)

| Part Name | Qty | Specification / Source | Cost |
| :--- | :--- | :--- | :--- |
| **Low-KV Brushless Motor** | 1 | 5010 75KV Brushless Motor | \$45.00 |
| **N52 Block Magnets** | 24 | N52 Neodymium (10mm  x  10mm  x  3mm) | \$24.00 |
| **Delrin Stock (POM-C)** | 1 | 100mm diameter, 150mm length | \$35.00 |
| **SDR-35 PVC Pipe** | 1 | 3-inch nominal diameter (2ft) | \$12.00 |
| **Igus xiros Bearings** | 2 | Polymer ball bearings (6mm  x  15mm  x  5mm) | \$18.00 |
| **Ceramic Thrust Bearing** | 1 | Si3N4 Ceramic (6mm  x  14mm  x  5mm) | \$15.00 |
| **NBR-70 O-Rings** | 4 | AS568-152 Nitrile O-rings | \$4.00 |
| **Stainless Steel Shaft** | 1 | 316 Ground Shafting (6mm  x  100mm) | \$8.00 |
| **Cruising Propeller** | 1 | APC 9x6 Carbon-Fiber Folding Propeller | \$22.00 |
| **Total Estimated Cost** | | | **\$183.00** |

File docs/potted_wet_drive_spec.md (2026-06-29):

# Design Document: Potted Wet-Running Direct-Drive System (Option A)
## Document ID: ESD-02-A
## Revision: 1.0

This document defines the complete technical design, mechanical integration, electrical parameters, and fabrication instructions for the **Potted Wet-Running Direct-Drive Propulsion System (Option A)** of the Blue-Water Rover ASV.

---

## 1. Mechanical Integration & Hydrodynamics

### 1.1 Structural Assembly
Option A uses a "flooded-rotor" design. The stator is permanently fixed and potted inside a central core, while the rotor cup and propeller spin directly in seawater around it.

```mermaid
graph TD
    subgraph StatorAssembly ["Stator Assembly (Fixed)"]
        Foil[Aluminum Keel Foil Spar] -->|Bolted| Collar[ASA Clam-shell Mount]
        Collar -->|Epoxy Bond| Core[Potted Stator Core]
        Core --> Shaft[Fixed 8mm Stainless Steel Shaft]
    end
    
    subgraph RotorAssembly ["Rotor Assembly (Rotating)"]
        Shaft --> Bearings[Dual ZrO2 Ceramic Bearings]
        Bearings --> Rotor[Aluminum Rotor Cup with N52SH Magnets]
        Rotor --> Prop[9-inch Carbon Fiber Propeller]
    end
    
    subgraph SiltProtection ["Silt Protection"]
        Rotor -.->|Labyrinth Interface| Collar
    end
```

### 1.2 Keel Spar Attachment
*   **Mounting Collar**: A hydrodynamic, split-clam shell collar printed in **ASA (Acrylonitrile Styrene Acrylate)** at 100\% infill. 
*   **Attachment**: Clamps to the bottom of the 8mm 6061-T6 aluminum foil spar. It is secured using two M5  x  25mm 316 stainless steel shoulder bolts passing through pre-drilled holes in the foil spar.
*   **Hydrodynamic fairing**: The collar transitions smoothly into a nose cone profile to minimize frontal area drag.

### 1.3 Labyrinth Silt-Exclusion Seal
To prevent sand and micro-algae from entering the 0.8 mm gap between the stator and rotor, the assembly incorporates a **labyrinth seal**:
*   **Geometry**: Concentric interlocking sleeves machined on the front face of the rotor cup and the rear face of the static mounting collar.
*   **Clearance**: A radial and axial gap of exactly 0.15 mm.
*   **Function**: Centrifugal forces from the spinning rotor cup throw entering particles outward, while the winding path prevents suspended silt from settling in the motor air gap.

---

## 2. Electrical, ESC & Thermal Specifications

### 2.1 Wiring and Conduit
*   **Phase Leads**: Three 16 AWG extra-flexible silicone-insulated copper wires.
*   **Conduit**: The wires exit the rear of the stator potting, run inside a protective polyurethane sleeve, and route upwards through a 5mm slot machined along the trailing edge of the aluminum foil spar to the deck electronics box.

### 2.2 VESC Field-Oriented Control (FOC) Configuration
To ensure smooth startup and torque tracking under water load, a VESC (or equivalent FOC ESC) must be calibrated with the following motor parameters:

| VESC Parameter | Recommended Setting | Description |
| :--- | :--- | :--- |
| **Motor Type** | FOC | Sinusoidal Field Oriented Control (sensorless) |
| **Motor Current Max**| 15.0 A | Limits peak current and thermal stress |
| **Absolute Max Current**| 25.0 A | Peak cutoff limit |
| **Motor Resistance (R)**| ~ 0.182 \Omega | Measured during motor detection |
| **Motor Inductance (L)**| ~ 145.2 \muH | Measured during motor detection |
| **Motor Flux Linkage** | ~ 0.0092 Wb | Measured during motor detection |
| **Switching Frequency**| 25.0 kHz | Minimizes acoustic noise and ripple |
| **Startup Boost** | 0.08 V | Initial voltage offset to break static inertia |
| **Observer Gain** | 1.50 | Increased by 50\% to stabilize rotor tracking in water |
| **Minimum ERPM** | 150 ERPM | Prevents commutation loss at low speeds |

### 2.3 Thermal Dissipation Modeling
Running a motor submerged in water offers exceptional cooling performance. The convective heat transfer coefficient of water (h_water) is:
h_water ~ 1,500 W/(m² * K)

The stator heat (P_loss) is conducted through the 0.8 mm potting layer of MG Chemicals 832TC epoxy (thermal conductivity k = 1.44 W/(m * K)):
R_thermal = (t) / (k  *  A_stator) ~ 0.05 K/W

At a continuous cruising power of 50W (with ~ 10W of electrical copper losses):
\Delta T_stator = P_loss  *  R_thermal ~ 10 W  *  0.05 K/W ~ 0.5°C

*   **Conclusion**: Stator thermal rise is negligible. The motor can run continuously at full rating without any risk of thermal degradation, even under high ambient deck temperatures.

---

## 3. Materials & Step-by-Step Fabrication Guide

### 3.1 Potting Mold & Degassing Setup
1.  **Preparation**: Print the stator casting mold in silicone or PLA (if PLA, coat the interior with PVA mold release).
2.  **Stator Preparation**: Wrap the stator lead wires in heat-shrink tubing at the exit point to prevent epoxy wicking. Position the stator concentrically in the mold using a central alignment pin.
3.  **Epoxy Mixing**: Mix MG Chemicals 832TC Parts A & B in a 1:1 weight ratio. Mix slowly to prevent air entrapment.
4.  **Vacuum Degassing**: Place the mixed epoxy in a vacuum chamber. Pull a vacuum of -29 in Hg and hold for 10 minutes. The epoxy will rise and collapse as air bubbles escape.
5.  **Pouring & Curing**: Pour the degassed epoxy into the mold slowly from one side to prevent air pockets. Cure in a dry oven at 65°C for 4 hours (or at room temperature for 24 hours).
6.  **Turning**: Mount the cured stator on a lathe. Turn down the outer epoxy surface until the outer diameter is smooth and matches the target air-gap clearance.
    *   *Epoxy and Plastic Turning Guidelines*: Stator epoxy turning shares similar thermal and tooling constraints with turning 3D-printed Nylon. Ensure the cutting tool is razor-sharp and take light, high-speed passes to prevent chipping or melting the resin. Refer to the [3D Printing Reference Document](file:///workspaces/BWR_ASV/docs/pontoon_3d_print_evaluation.md#L68-L76) for specific tooling parameters.

### 3.2 Ceramic Bearing Fitting
1.  Use **full ZrO_2 (Zirconium Dioxide) open bearings** (8mm  x  16mm  x  5mm).
2.  Do not use any grease, oil, or shields.
3.  Press-fit the bearings into the rotor cup seats using a dedicated bearing press tool. Ensure the outer race is supported during installation to avoid cracking the ceramic rings.

### 3.3 Rotor Magnet Encapsulation
1.  Verify the N52SH magnets are free of surface defects. Glue them into the aluminum rotor cup using marine epoxy (West System 105/205).
2.  Wrap the outer surface of the magnets with 0.2mm carbon-fiber prepreg tape, tensioning it tightly.
3.  Cure the wrap at 80°C to shrink and bond the carbon fiber, forming a permanent hoop-stress sleeve that prevents magnets from delaminating or corroding.

---
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

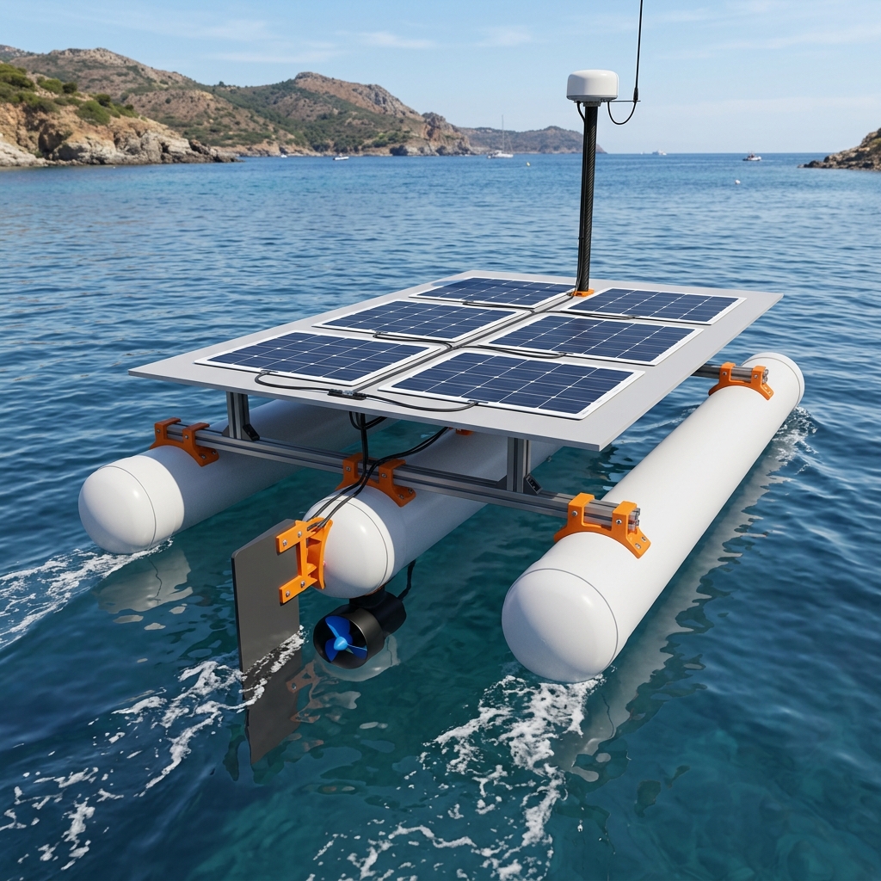
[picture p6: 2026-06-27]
docs/asv_option_d_realistic.png

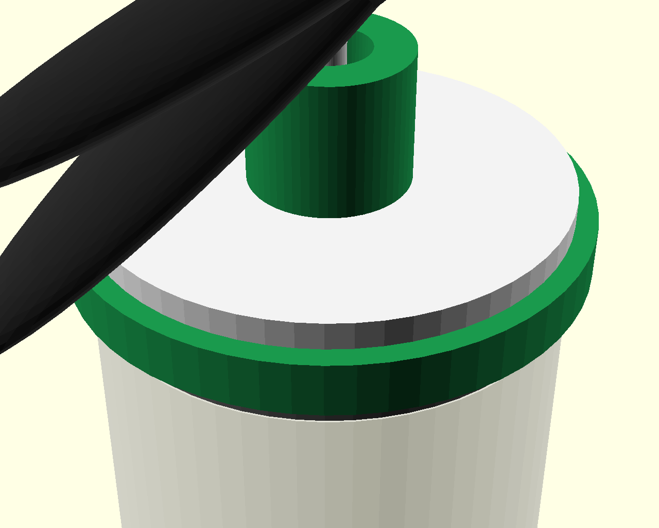
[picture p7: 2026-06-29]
magnetic_coupling_drive_render.png

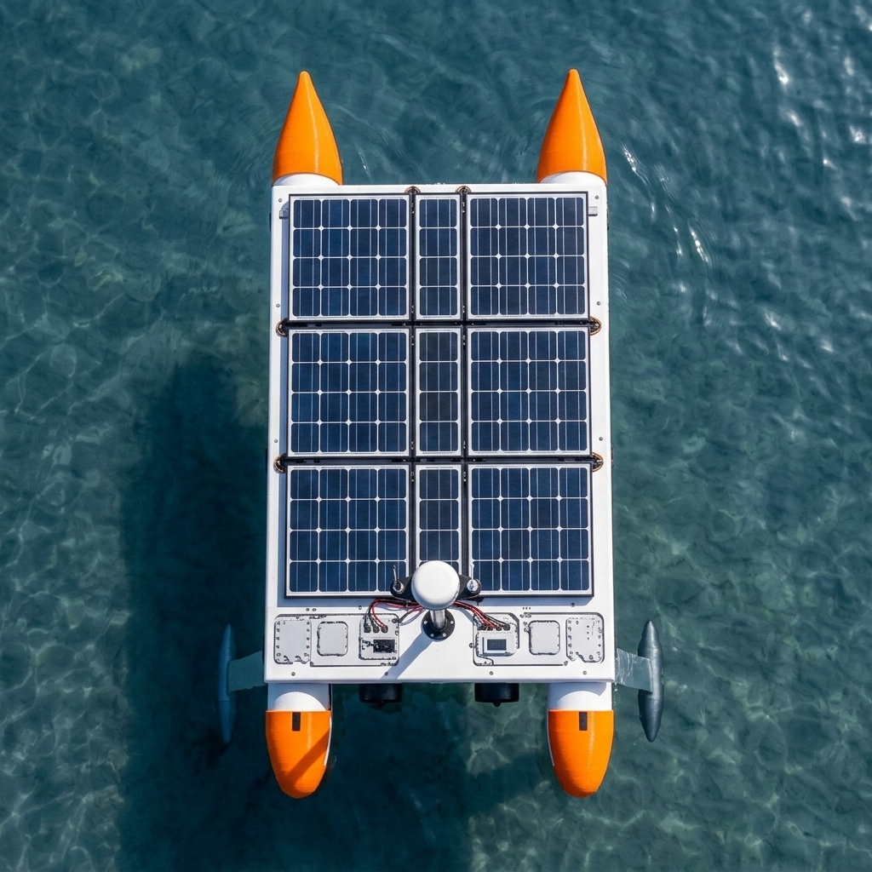
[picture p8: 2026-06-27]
docs/asv_option_f_top_view.png

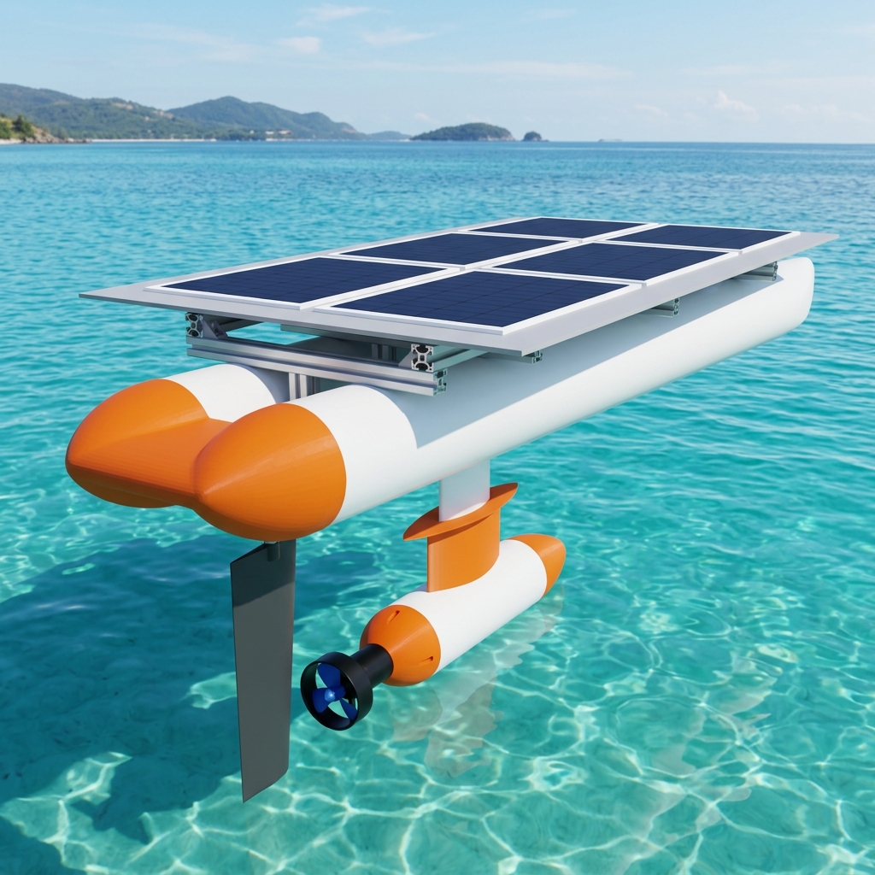
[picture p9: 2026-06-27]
docs/asv_option_e_realistic_exposed.png

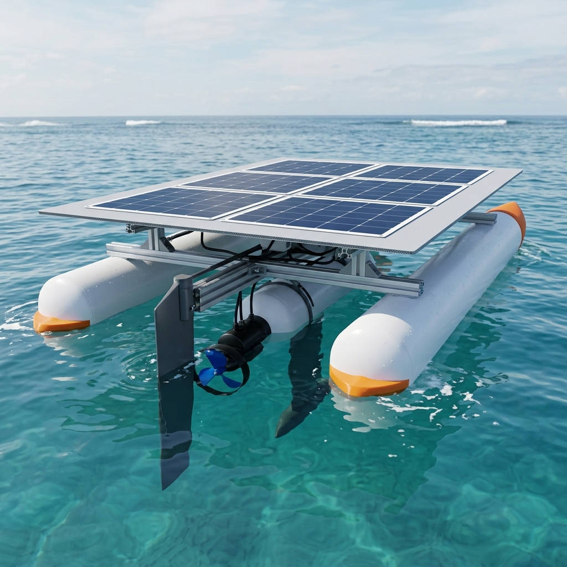
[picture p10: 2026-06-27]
asv_option_e_realistic_submerged_only.png

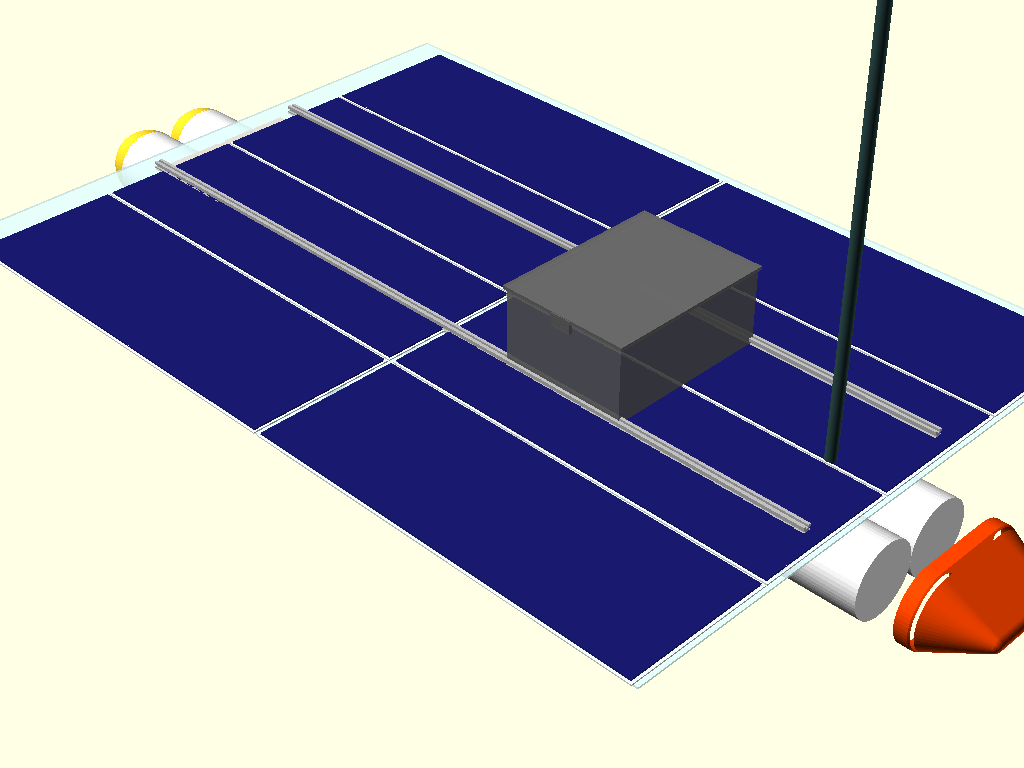
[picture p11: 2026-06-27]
docs/asv_option_e_render.png

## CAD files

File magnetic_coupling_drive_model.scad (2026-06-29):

// Project Blue-Water Rover ASV - ESD-02-B
// Design Option B: Coaxial Magnetic Coupling Propulsion Model
//
// Open this file in OpenSCAD (https://openscad.org) to view the assembly.

$fn = 60; // Curve resolution

// Color constants
color_pvc = [0.7, 0.7, 0.75, 0.4];          // Translucent grey PVC
color_delrin = [0.95, 0.95, 0.95, 1.0];       // White Delrin
color_oring = [0.1, 0.1, 0.1, 1.0];           // Black rubber O-rings
color_motor = [0.8, 0.5, 0.1, 1.0];          // Motor coils/housing (orange/silver)
color_hub = [0.4, 0.4, 0.4, 1.0];            // Back-iron steel hubs
color_magnet_n = [0.8, 0.2, 0.2, 1.0];      // North magnets (red)
color_magnet_s = [0.2, 0.2, 0.8, 1.0];      // South magnets (blue)
color_shaft = [0.85, 0.85, 0.85, 1.0];      // Stainless steel shaft
color_polymer = [0.6, 0.6, 0.6, 1.0];        // Igus xiros polymer bearings
color_ceramic = [0.93, 0.93, 0.91, 1.0];     // Ceramic thrust bearing (ivory)
color_prop = [0.15, 0.15, 0.15, 1.0];       // Propeller (black)
color_collar = [0.1, 0.6, 0.3, 1.0];        // Mounting collar (green)

// Model dimensions (mm)
pvc_od = 88.9;        // 3-inch SDR-35 PVC outer diameter
pvc_id = 82.2;        // 3-inch SDR-35 PVC inner diameter
pvc_length = 120.0;
delrin_dia = pvc_id;
barrier_thickness = 1.5;
magnet_gap = 2.5;     // Total gap between internal and external magnets

// Explode distance
explode = 0.0; // Set to >0 in OpenSCAD to see internal parts

module dry_chamber() {
    // PVC dry tube
    color(color_pvc)
    difference() {
        cylinder(d=pvc_od, h=pvc_length, center=true);
        cylinder(d=pvc_id, h=pvc_length + 2, center=true);
    }
}

module delrin_cap() {
    // Machined Delrin cap with O-ring grooves and thin barrier face
    color(color_delrin)
    difference() {
        union() {
            // Main plug body
            cylinder(d=delrin_dia, h=30, center=true);
            // Flange collar matching PVC OD
            translate([0, 0, 15 + 2.5])
            cylinder(d=pvc_od, h=5, center=true);
        }
        // Hollow internal cup for internal magnet hub
        translate([0, 0, -5])
        cylinder(d=delrin_dia - 10, h=30, center=true);
        
        // O-ring grooves (AS568-152)
        // Two radial grooves on the plug body
        translate([0, 0, -8])
        difference() {
            cylinder(d=delrin_dia + 2, h=3.6, center=true);
            cylinder(d=delrin_dia - 4.04, h=4, center=true);
        }
        translate([0, 0, 2])
        difference() {
            cylinder(d=delrin_dia + 2, h=3.6, center=true);
            cylinder(d=delrin_dia - 4.04, h=4, center=true);
        }
    }
    
    // O-rings (representing Nitrile rings placed in the grooves)
    color(color_oring) {
        translate([0, 0, -8])
        difference() {
            cylinder(d=delrin_dia - 0.2, h=2.6, center=true);
            cylinder(d=delrin_dia - 5.0, h=3, center=true);
        }
        translate([0, 0, 2])
        difference() {
            cylinder(d=delrin_dia - 0.2, h=2.6, center=true);
            cylinder(d=delrin_dia - 5.0, h=3, center=true);
        }
    }
}

module brushless_motor() {
    // Internal 5010 brushless motor
    color([0.3, 0.3, 0.35, 1.0]) // Stator
    cylinder(d=50, h=10, center=true);
    color(color_motor) // Copper windings
    for (i = [0:11]) {
        rotate([0, 0, i * 30])
        translate([18, 0, 0])
        cylinder(d=10, h=8, center=true);
    }
    // Rotor cup and shaft
    color([0.8, 0.8, 0.85, 1.0]) {
        translate([0, 0, 8])
        cylinder(d=50, h=6, center=true);
        translate([0, 0, 15])
        cylinder(d=8, h=20, center=true);
    }
}

module magnet_coupling_hub(internal=true) {
    dia = internal ? delrin_dia - 16 : delrin_dia + 6;
    h_len = 15;
    
    // Steel back-iron ring
    color(color_hub)
    difference() {
        cylinder(d=dia, h=h_len, center=true);
        cylinder(d=dia-6, h=h_len+2, center=true);
    }
    
    // Neodymium magnets (12 poles)
    for (i = [0:11]) {
        rotate([0, 0, i * 30]) {
            translate([internal ? dia/2 - 2 : dia/2 - 4, 0, 0])
            color(i % 2 == 0 ? color_magnet_n : color_magnet_s)
            cube([3, 10, 10], center=true);
        }
    }
}

module polymer_bearing() {
    // Igus xiros polymer bearing
    color(color_polymer)
    difference() {
        cylinder(d=15, h=5, center=true);
        cylinder(d=6, h=6, center=true);
    }
}

module ceramic_thrust_washer() {
    // Silicon Nitride ceramic thrust bearing
    color(color_ceramic)
    difference() {
        cylinder(d=14, h=2, center=true);
        cylinder(d=6.2, h=3, center=true);
    }
}

module wet_bracket() {
    // ASA bracket holding external shaft and bearings
    color(color_collar)
    difference() {
        union() {
            // Main ring clamping Delrin cap
            cylinder(d=pvc_od + 8, h=10, center=true);
            // Struts extending aft
            translate([0, 0, 20])
            cylinder(d=30, h=30, center=true);
        }
        // Inner bore matching Delrin cap flange
        cylinder(d=pvc_od, h=12, center=true);
        // Shaft and bearing seat passage
        translate([0, 0, 20])
        cylinder(d=15.1, h=35, center=true);
    }
}

module propeller() {
    // Folding hub
    color(color_prop)
    cylinder(d=20, h=10, center=true);
    
    // Blades (folded)
    for (dir = [-1, 1]) {
        translate([dir * 10, 0, 0])
        rotate([dir * 15, 5, dir * 90])
        color(color_prop)
        scale([1, 0.1, 0.05])
        translate([0, 100, 0])
        sphere(r=100);
    }
}

// --- ASSEMBLY VIEW ---
// Dry PVC Tube
translate([0, 0, -pvc_length/2]) dry_chamber();

// Internal Motor (Fixed inside tube)
translate([0, 0, -45]) rotate([180, 0, 0]) brushless_motor();

// Internal Magnet Hub (on motor shaft, close to cap)
translate([0, 0, -15 - explode]) magnet_coupling_hub(internal=true);

// Delrin Cap (sealing the end of the tube)
translate([0, 0, 0]) delrin_cap();

// Wet Side Bracket (holding external shaft)
translate([0, 0, 10]) wet_bracket();

// External Magnet Hub (Wet side)
translate([0, 0, 5 + magnet_gap + explode]) magnet_coupling_hub(internal=false);

// Ceramic Thrust Washer (bearing the axial attraction load)
translate([0, 0, 15 + explode]) ceramic_thrust_washer();

// Polymer Bearings (supporting the wet shaft)
translate([0, 0, 25 + explode]) polymer_bearing();
translate([0, 0, 35 + explode]) polymer_bearing();

// Wet-Side Shaft
translate([0, 0, 28 + explode])
color(color_shaft)
cylinder(d=6, h=55, center=true);

// Propeller (attached to external shaft)
translate([0, 0, 60 + explode * 2]) propeller();

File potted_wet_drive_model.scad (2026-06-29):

// Project Blue-Water Rover ASV - ESD-02-A
// Design Option A: Potted Wet-Running Direct-Drive Propulsion Model
//
// Open this file in OpenSCAD (https://openscad.org) to view the assembly.

$fn = 60; // Curve resolution

// Color constants
color_stator_epoxy = [0.8, 0.4, 0.1, 0.9]; // Potted epoxy (translucent orange-brown)
color_stator_metal = [0.3, 0.3, 0.3, 1.0]; // Steel core
color_rotor = [0.5, 0.5, 0.55, 0.8];       // Aluminum rotor (translucent)
color_magnet_n = [0.8, 0.2, 0.2, 1.0];      // North magnets (red)
color_magnet_s = [0.2, 0.2, 0.8, 1.0];      // South magnets (blue)
color_ceramic = [0.93, 0.93, 0.91, 1.0];     // ZrO2 Ceramic (ivory)
color_collar = [0.1, 0.6, 0.3, 1.0];        // ASA collar (green)
color_foil = [0.75, 0.75, 0.75, 0.8];       // Aluminum spar (translucent)
color_prop = [0.15, 0.15, 0.15, 1.0];       // Carbon fiber prop
color_shaft = [0.85, 0.85, 0.85, 1.0];      // Stainless steel shaft
color_anode = [0.6, 0.6, 0.7, 1.0];         // Zinc anode

// Model dimensions (mm)
stator_dia = 50.0;
stator_length = 35.0;
air_gap = 0.8;
rotor_thickness = 3.0;
rotor_dia = stator_dia + 2 * air_gap + 2 * rotor_thickness;
rotor_length = 40.0;
shaft_dia = 8.0;
shaft_length = 120.0;

// Explode distance for viewing internal parts
explode = 0.0; // Set to >0 in OpenSCAD to see internal parts

module foil_spar() {
    // 8mm thick aluminum foil profile (approximate NACA 0012)
    color(color_foil)
    linear_extrude(height=150)
    scale([1, 0.15])
    difference() {
        circle(d=80);
        translate([40, -40]) square([80, 80]); // trailing edge taper
    }
}

module mounting_collar() {
    // ASA split collar clamping the foil and housing the shaft
    color(color_collar)
    difference() {
        union() {
            // Main cylindrical body
            cylinder(d=65, h=50, center=true);
            // Wing clamping the foil spar
            translate([0, 30, 25])
            cube([25, 60, 100], center=true);
        }
        // Slot for foil spar
        translate([0, 30, 25])
        cube([8.2, 80, 110], center=true);
        // Shaft passage
        cylinder(d=22, h=60, center=true);
        // Bolt holes
        translate([0, 45, 50]) rotate([0, 90, 0]) cylinder(d=5.2, h=40, center=true);
        translate([0, 45, 0]) rotate([0, 90, 0]) cylinder(d=5.2, h=40, center=true);
    }
}

module stator_core() {
    // Stator coils and teeth
    color(color_stator_metal)
    cylinder(d=shaft_dia+4, h=stator_length, center=true);
    
    // Teeth and windings (12 slots)
    for (i = [0:11]) {
        rotate([0, 0, i * 30]) {
            // Steel tooth
            color(color_stator_metal)
            translate([stator_dia/4 + 2, 0, 0])
            cube([stator_dia/2 - 4, 4, stator_length], center=true);
            
            // Copper windings potted in epoxy
            color(color_stator_epoxy)
            translate([stator_dia/3 + 1, 0, 0])
            cube([8, 12, stator_length - 2], center=true);
        }
    }
}

module rotor_cup() {
    color(color_rotor)
    difference() {
        union() {
            // Outer bell
            cylinder(d=rotor_dia, h=rotor_length, center=true);
            // Rear hub
            translate([0, 0, -rotor_length/2 - 5])
            cylinder(d=20, h=10, center=true);
        }
        // Hollow interior
        translate([0, 0, 2])
        cylinder(d=rotor_dia - 2*rotor_thickness, h=rotor_length + 2, center=true);
        // Shaft bore
        cylinder(d=shaft_dia, h=100, center=true);
    }
    
    // Magnets inside the cup wall (14 poles)
    for (i = [0:13]) {
        rotate([0, 0, i * (360/14)])
        translate([stator_dia/2 + air_gap + 0.5, 0, 0])
        color(i % 2 == 0 ? color_magnet_n : color_magnet_s)
        cube([1.5, 8, stator_length], center=true);
    }
}

module ceramic_bearing() {
    // Open ZrO2 bearing
    color(color_ceramic)
    difference() {
        cylinder(d=16, h=5, center=true);
        cylinder(d=8, h=6, center=true);
    }
    // Balls representation
    for (i = [0:7]) {
        rotate([0, 0, i * 45])
        translate([6, 0, 0])
        color("White")
        sphere(d=3);
    }
}

module propeller() {
    // Folding hub
    color(color_prop)
    cylinder(d=24, h=12, center=true);
    
    // Blades (folded back slightly for rendering)
    for (dir = [-1, 1]) {
        translate([dir * 12, 0, 0])
        rotate([dir * 15, 5, dir * 90])
        color(color_prop)
        scale([1, 0.1, 0.05])
        translate([0, 100, 0])
        sphere(r=100);
    }
}

// --- ASSEMBLY VIEW ---
// Foil Spar
translate([0, 30, 45]) foil_spar();

// Mounting Collar
mounting_collar();

// Fixed Shaft
color(color_shaft)
cylinder(d=shaft_dia, h=shaft_length, center=true);

// Ceramic Bearings
translate([0, 0, -15]) ceramic_bearing();
translate([0, 0, 15]) ceramic_bearing();

// Stator (Fixed in middle)
stator_core();

// Rotor (Exploded or assembled)
translate([0, 0, -explode]) {
    rotor_cup();
}

// Zinc Anode (on exposed shaft behind rotor)
translate([0, 0, -rotor_length/2 - 12])
color(color_anode)
difference() {
    cylinder(d=16, h=8, center=true);
    cylinder(d=shaft_dia, h=10, center=true);
}

// Propeller (at the bottom/rear shaft end)
translate([0, 0, rotor_length/2 + 25 + explode]) {
    propeller();
}

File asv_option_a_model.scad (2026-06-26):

// Project Blue-Water Rover ASV - Option A (2.53m Proportional Scale Catamaran)
//
// This file renders a complete, parametric 3D model of the Option A catamaran,
// incorporating PVC hulls, 2020 aluminum extrusion frame, 3D printed brackets,
// Coroplast deck, flexible solar panels, power boxes, thrusters, and mast.
//
// Open this file in OpenSCAD (https://openscad.org) to view the assembly.

$fn = 60; // Curve resolution for rendering performance

// --- DIMENSIONS & CONFIGURATION ---
// Option A specific parameters
pvc_od = 219.1;           // 8" Schedule 40 PVC Outer Diameter (mm)
hull_length = 2530.0;     // Hull length (mm)
overall_beam = 1600.0;    // Overall width of the boat (mm)
hull_spacing = overall_beam - pvc_od; // Center-to-center hull distance (mm)

// Frame Configuration (2020 extrusion)
extrusion_size = 20.0;    // 20mm x 20mm extrusion
crossbeam_length = 1600.0;
num_crossbeams = 4;
// Y positions of the four transverse crossbeams
crossbeam_y = [300.0, 900.0, 1500.0, 2100.0];

// Longitudinal rails
long_rail_length = 1900.0; // Spans from rear to front crossbeams
long_rail_x = [-350.0, 350.0]; // Extrusions to mount dry boxes & support deck

// Mounting Bracket Parameters (matching pvc_extrusion_bracket.scad preset A)
bracket_width = 140.0;
bracket_length = 50.0;
cradle_depth = 15.0;
top_thickness = 15.0;
extrusion_width = 20.2;
extrusion_depth = 3.0;

// Thickness of rubber friction/dampening strip between bracket and PVC (mm)
rubber_thickness = 1.5;

// Calculated Z-offsets
pipe_radius = pvc_od / 2 + rubber_thickness;
block_top_z = pipe_radius + top_thickness; // Top surface of mounting bracket
frame_z = block_top_z - extrusion_depth;   // Z coordinate of frame bottom
deck_z = frame_z + extrusion_size;         // Z coordinate of deck surface

// Display Controls (1 = show, 0 = hide)
show_hulls = 1;
show_frame = 1;
show_brackets = 1;
show_deck = 1;
show_solar = 1;
show_boxes = 1;
show_thrusters = 1;
show_mast = 1;


// --- MODULES ---

// 1. PVC-to-2020 Bracket Module (Redefined locally to avoid scope conflicts)
module pvc_2020_bracket() {
    bolt_diameter = 5.3;
    counterbore_diameter = 9.5;
    counterbore_depth = 7.0;
    clamp_width = 14.5;
    clamp_thickness = 3.0;
    
    block_bottom_z = pipe_radius - cradle_depth;
    block_height = block_top_z - block_bottom_z;
    
    difference() {
        // Main block
        translate([-bracket_width/2, -bracket_length/2, block_bottom_z])
            cube([bracket_width, bracket_length, block_height]);
        
        // PVC hull cutout
        translate([0, -bracket_length/2 - 1, 0])
            rotate([-90, 0, 0])
                cylinder(r=pipe_radius, h=bracket_length + 2);
        
        // Extrusion slot
        translate([-extrusion_width/2, -bracket_length/2 - 1, block_top_z - extrusion_depth])
            cube([extrusion_width, bracket_length + 2, extrusion_depth + 1]);
        
        // Mounting bolt holes
        for (y_offset = [-12.5, 12.5]) {
            translate([0, y_offset, block_bottom_z - 1])
                cylinder(d=bolt_diameter, h=block_height + 2);
            translate([0, y_offset, block_top_z - counterbore_depth])
                cylinder(d=counterbore_diameter, h=counterbore_depth + 1);
        }
        
        // Hose clamp channel
        translate([0, -clamp_width/2, 0])
            rotate([-90, 0, 0])
                difference() {
                    cylinder(r=pipe_radius + clamp_thickness, h=clamp_width);
                    translate([0, 0, -1])
                        cylinder(r=pipe_radius, h=clamp_width + 2);
                }
    }
}

// 2. 2020 Aluminum Extrusion Bar
module aluminum_extrusion(length) {
    color("silver") {
        difference() {
            // Main solid bar
            cube([extrusion_size, length, extrusion_size]);
            
            // Subtract grooves on 4 sides (T-slots) for realism
            groove_w = 6.0;
            groove_d = 5.0;
            
            // Top groove
            translate([extrusion_size/2 - groove_w/2, -1, extrusion_size - groove_d])
                cube([groove_w, length + 2, groove_d + 1]);
            // Bottom groove
            translate([extrusion_size/2 - groove_w/2, -1, -1])
                cube([groove_w, length + 2, groove_d + 1]);
            // Left groove
            translate([-1, extrusion_size/2 - groove_w/2, extrusion_size/2 - groove_w/2])
                cube([groove_d + 1, length + 2, groove_w]);
            // Right groove
            translate([extrusion_size - groove_d, -1, extrusion_size/2 - groove_w/2])
                cube([groove_d + 1, length + 2, groove_w]);
        }
    }
}

// 3. PVC Hull Pontoon with Domed End Caps
module pvc_hull() {
    color("white") {
        // Main cylinder body
        translate([0, pipe_radius, 0])
            rotate([-90, 0, 0])
                cylinder(r=pipe_radius, h=hull_length - pvc_od);
        
        // Rear domed end-cap
        translate([0, pipe_radius, 0])
            sphere(r=pipe_radius);
        
        // Front domed end-cap
        translate([0, hull_length - pipe_radius, 0])
            sphere(r=pipe_radius);
    }
}

// 4. Thruster Module (resembling BlueRobotics T200)
module thruster() {
    color("black") {
        // Main motor body
        rotate([-90, 0, 0])
            cylinder(d=60, h=110, center=true);
        // Motor nose cone
        translate([0, -55, 0])
            rotate([90, 0, 0])
                cylinder(d1=60, d2=30, h=25);
        
        // Shroud/nozzle surrounding the prop
        difference() {
            translate([0, 20, 0])
                rotate([-90, 0, 0])
                    cylinder(d=95, h=65, center=true);
            translate([0, 20, 0])
                rotate([-90, 0, 0])
                    cylinder(d=85, h=67, center=true);
        }
        
        // Propeller hub and blades
        color("dodgerblue") {
            translate([0, 30, 0]) {
                rotate([-90, 0, 0])
                    cylinder(d=22, h=25, center=true);
                // 3 blades
                for (angle = [0, 120, 240]) {
                    rotate([0, angle, 0])
                        translate([0, 0, 10])
                            cube([10, 35, 2], center=true);
                }
            }
        }
    }
    
    // Acetal/PETG Mounting Bracket to PVC Hull
    color("dimgray") {
        translate([0, -20, 45])
            cube([25, 60, 50], center=true);
        translate([0, -20, 75])
            cube([bracket_width, 15, 15], center=true);
    }
}

// 5. Watertight Dry Box Enclosure (Power Vault)
module dry_box() {
    box_w = 400;
    box_l = 300;
    box_h = 180;
    
    color("dimgray", 0.9) {
        // Base container
        difference() {
            cube([box_w, box_l, box_h], center=true);
            translate([0, 0, 5])
                cube([box_w - 10, box_l - 10, box_h], center=true);
        }
        // Snap-lock lid
        translate([0, 0, box_h/2 + 2])
            cube([box_w + 10, box_l + 10, 8], center=true);
        
        // Lock latches (colored blue)
        color("dodgerblue") {
            for (x_offset = [-box_w/2 - 4, box_w/2 + 4]) {
                translate([x_offset, 0, box_h/2 - 10])
                    cube([6, 50, 30], center=true);
            }
        }
    }
}

// 6. Sensor Mast and Antenna Array
module sensor_mast() {
    mast_h = 1200;
    mast_d = 25;
    
    // Carbon fiber mast pole
    color("darkslategray") {
        cylinder(d=mast_d, h=mast_h);
    }
    
    // Top mount platform
    color("black") {
        translate([0, 0, mast_h])
            cylinder(d=100, h=10);
    }
    
    // White RTK-GPS Dome
    color("white") {
        translate([-25, 0, mast_h + 10])
            cylinder(d=80, h=30);
    }
    
    // LoRa Whip Antenna
    color("black") {
        translate([30, 20, mast_h + 10])
            cylinder(d=5, h=250);
        translate([30, 20, mast_h + 10])
            cylinder(d=12, h=30); // base
    }
    
    // Optical Avoidance Camera Box
    color("gray") {
        translate([0, -40, mast_h + 20]) {
            cube([40, 40, 40], center=true);
            // Camera lens
            color("black")
                translate([0, -21, 0])
                    rotate([-90, 0, 0])
                        cylinder(d=15, h=3);
        }
    }
}

// 7. Rubber Friction & Dampening Sleeve between Hull and Bracket
module rubber_sleeve() {
    color("black") {
        rotate([-90, 0, 0])
            difference() {
                // outer sleeve matching bracket cradle cutout radius
                cylinder(r=pvc_od/2 + rubber_thickness, h=bracket_length, center=true);
                // inner sleeve fitting tightly on PVC OD
                translate([0, 0, -1])
                    cylinder(r=pvc_od/2, h=bracket_length + 2, center=true);
            }
    }
}
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

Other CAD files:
asv_option_a_printed_model.scad
asv_option_d_model.scad
asv_option_e_model.scad
asv_option_f_model.scad
pvc_extrusion_bracket.scad

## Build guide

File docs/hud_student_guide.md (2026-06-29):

# Cadet's Guide: How to Use the Blue-Water Rover HUD!
## Welcome to the Mission Control Center!

Hello, future roboticist! You are looking at the **Heads-Up Display (HUD)** for the Blue-Water Rover—an autonomous solar catamaran sailing 700 miles along the Florida coast. 

Think of this dashboard as your spaceship control panel. Here is how to access it, read the dials, and take command of the vessel!

---

## 1. How to Launch the HUD

1.  **Start the Engine**: The server code should already be running. If not, open your computer terminal and type:
    ```bash
    python3 src/main.py
    ```
2.  **Open the Viewscreen**: Open any web browser (like Chrome or Safari) and go to this web address:
    `http://localhost:5000`

You will see a glowing, sci-fi style dashboard. Let’s learn what all the glowing parts mean!

---

## 2. Reading Your Instruments

The screen is split into three main sections:

```
+---------------------------------------------------------------------------------+
|                               HUD SCREEN LAYOUT                                 |
+---------------------------------------------------------------------------------+
|   SECTION 1: Power Vitals      |   SECTION 2: Radar & Map   | SECTION 3: Console|
|   - Battery Level (Green Ring) |   - Rotating Compass Rose  | - Big Red KILL    |
|   - Solar Input vs Motor Draw  |   - Obstacle Sonar (D455)  | - Waypoint Form   |
|   - Rudder & Throttle Bars     |   - SVG Florida Coast Map  | - Live Packet Log |
+---------------------------------------------------------------------------------+
```

### 1. The Energy Tank (Section 1 - Left)
*   **Battery Level (Green Ring)**: Shows how full the batteries are. 100% means fully charged!
*   **Net Balance (Amber Ring)**: Tells you if you are making energy or losing it. 
    *   *Positive (+)*: Making power (sun is bright!).
    *   *Negative (-)*: Draining power (motors are running fast!).
*   **Solar Harvest**: Watts generated by solar panels.
*   **Propulsion Draw**: Watts consumed by the thruster motor.
*   **Throttle & Rudder Bars**: Visual indicators showing how much power the motor is using and how far left or right the rudder is turned.

### 2. Scanning the Sea (Section 2 - Center)
*   **The Compass Rose**: A circle showing North, East, South, and West.
    *   *Blue Pointer*: The direction the boat is heading.
    *   *Amber Pointer*: The direction of the next waypoint target.
*   **Proximity Sonar**: A half-circle divided into **Left, Center, and Right** wedges. This represents the **Intel RealSense D455** camera's eyes:
    *   *Green/Clear*: No obstacles.
    *   *Yellow*: An obstacle is detected within 10 meters (caution!).
    *   *Red*: An obstacle is extremely close (< 6 meters). The autopilot will swerve automatically to avoid it!
*   **Coastline Map**: An interactive map tracking the boat as it sails from Charleston, SC, around the Florida Keys, to Tampa Bay!

### 3. Taking the Helm (Section 3 - Right)
*   **The Big Red Button (EMERGENCY MOTOR KILL)**: Clicking this immediately cuts all motor power. The boat will float safely in place.
*   **Switch to Auto / Manual**: Toggle between manual RC remote steering or letting the autopilot steer.
*   **Inject Waypoint**: Enter target Latitude and Longitude numbers (global coordinates) and click "Inject" to send the boat to a new destination!
*   **Serial Log**: The scrolling green text at the bottom is the raw messaging feed. This is the code sending telemetry diagnostic packages (beginning with `$TEL:DIAG`) back to the base station.

---

## 3. Mission Experiments to Try!

Become a test pilot by trying these operations:

1.  **Test Autonomous Sailing**:
    *   Click the **SWITCH TO AUTO** button.
    *   Watch the mode badge turn green and read `AUTO`.
    *   Look at the compass: the boat will automatically steer toward the target waypoint.
2.  **Avoid an Obstacle**:
    *   In the map or simulator view, watch the proximity sonar sectors change color as mock buoys and land approach.
    *   Watch the rudder bar deflection respond to steer away from the yellow/red zones!
3.  **Perform a Rescue Stop**:
    *   Press the **EMERGENCY MOTOR KILL** button.
    *   Watch the HUD header display `EMERGENCY KILLED` in red text. The throttle bar will immediately drop to 0.
    *   To start sailing again, click the grey **RESET SHUTDOWN** button.

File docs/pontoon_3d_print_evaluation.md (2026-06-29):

# Engineering Evaluation: 3D Printing Catamaran Pontoons for Option A

This report evaluates the feasibility of 3D printing the dual 2.53m (219.1mm OD) pontoon hulls for the Option A Autonomous Surface Vehicle (ASV), comparing it to the baseline off-the-shelf Schedule 40 PVC pipe solution.

---

## 1. Executive Summary

While **Schedule 40 PVC** provides unmatched impact durability and structural strength, its extreme weight (12.5 kg/m for 8" pipe) introduces a severe displacement deficit, causing the vessel to float with a >75\% draft. 

**3D printing the pontoons** using **ASA (Acrylic Styrene Acrylonitrile)** is a structurally viable alternative that saves over **50 kg of deadweight** and enables safety features like internal watertight bulkheads. However, it requires printing the hull in 10–12 modular segments, reinforcing them with an internal tension rod, and coating them in marine epoxy to ensure watertightness.

### Recommendation
* **Preferred Path**: Utilize thin-walled **SDR-35 PVC / Sewer Pipe** (3.8 kg/m) or rotomolded HDPE pontoons first. They offer the weight-saving benefits of 3D printing without the high labor, seam-weakness, and porosity risks.
* **If 3D Printing is Chosen**: Print modular segments using **ASA** with a minimum of 4 perimeters, join them with an internal carbon fiber structural spar in tension, and seal the entire hull inside and out with marine-grade epoxy (e.g., West System 105/205).

---

## 2. Engineering Comparison Table

| Metric | Schedule 40 PVC (8" Pipe) | 3D Printed Modular Hulls (ASA) | Alternative: Thin-Walled SDR-35 PVC |
| :--- | :--- | :--- | :--- |
| **Material Weight** | 12.5 kg/m (Very Heavy) | ~ 2.0 kg/m (Very Light) | 3.8 kg/m (Light) |
| **Total Hull Weight (Pair)** | ~ 63.3 kg | ~ 10.1 kg | ~ 19.2 kg |
| **Reserve Buoyancy (190kg Max)** | 27\% (High risk of deck wash) | **49\% (Optimal draft)** | 44\% (Good draft) |
| **Structural Integrity** | Indestructible (Continuous extruded) | Moderate-Low (Prone to seam shear) | High (Continuous extruded) |
| **Watertightness** | 100\% (Non-porous) | Porous (Requires epoxy sealing) | 100\% (Non-porous) |
| **Internal Safety** | Single chamber (Single leak sinks hull) | **Multi-bulkhead (Fail-safe)** | Single chamber |
| **Fabrication Time** | <2 hours (Simple cuts) | >300 print hours | <2 hours |
| **Material Cost** | ~ \150–\200 | ~ \250 (Filament) +  \80 (Epoxy)| ~ \60–\100 |

---

## 3. Detailed Engineering Analysis

### 3.1 Weight & Hydrodynamic Displacement
*   **The Schedule 40 Bottleneck**: 8" Schedule 40 PVC is rated for high pressure and has a massive 8.18mm wall thickness. A pair of 2.53m hulls weighs 63.3kg. Combined with the 85kg dry payload (batteries, frame, solar panels), the total ASV weight becomes 148.3kg. Against a total displaced volume of 190.8L (buoyancy limit), the boat sits at a **77\% draft**. Waves will constantly wash over the deck, reducing MPPT solar efficiency due to splash residue and increasing drag.
*   **3D Printed Advantage**: By utilizing a 3mm shell thickness and internal gyroid infill (10–15\%), a 3D-printed pontoon weighs just ~ 5kg per side (10.1kg total). The ASV's total weight drops to 95.1kg, yielding a **50\% draft**—the optimal hydrodynamic waterline for a catamaran.

### 3.2 Material Selection for Marine 3D Printing
*   > [!WARNING]
    > **PLA is Unacceptable**: PLA has low UV resistance, absorbs water, and has a low glass transition temperature (60°C). Direct summer sunlight in Florida can easily heat dark or even white hulls past this point, causing catastrophic sagging and warping.
*   **PETG**: Good UV resistance and chemically inert. However, it can creep under continuous load (such as the clamping force of the frame brackets) and is difficult to glue.
*   **ASA (Acrylic Styrene Acrylonitrile) - Recommended**: ASA is highly UV-resistant, has excellent impact strength, handles higher temperatures (95°C glass transition), and can be solvent-welded using acetone. It is the gold-standard filament for structural brackets and exterior components.
*   **Nylon (Polyamide) - Conditional**: Extremely tough and impact-resistant, making it ideal for structural parts like the magnetic coupling pressure barrier or motor collars. 
    *   *Moisture Absorption Trap*: Standard **PA6 (Nylon 6)** absorbs up to 8–9\% water, causing severe swelling (2–3\%) and warping when submerged. This will distort O-ring grooves and close critical clearances (like the 0.5 mm magnetic coupling gap).
    *   *Recommended Grade*: Use **PA12 (Nylon 12)** or **PA12-CF (Carbon-Fiber Filled Nylon)**, which has a low moisture absorption rate (~ 1.5\% at saturation) and high dimensional stability.

### 3.3 Manufacturing Constraints (Seams & Watertightness)
1.  **Modular Assembly**: A 2.53m hull exceeds the build envelope of standard 3D printers. The hulls must be sliced into 10–12 modular segments of ~ 220mm length.
2.  **Porosity & Delamination**: FDM prints have micro-voids between layers. Over a 700 NM voyage (7–10 days of continuous submersion), hydrostatic pressure will force water through these micro-voids, slowly waterlogging the hulls.
3.  **Post-Processing & Watertight Sealing**: All submerged 3D-printed parts (hulls, motor pods, pressure caps) require post-print sealing. 
    *   *Epoxy Coating*: Coat the inner and outer surfaces with a low-viscosity marine-grade epoxy (e.g., West System 105/205 or XTC-3D) to fill the gaps between layers.
    *   *Infill and Wall Settings*: Parts requiring watertight seals should be printed with **100% infill** and high perimeter settings (4-5 walls).
    *   *Sealing Face Preparation*: Gland seats and O-ring contact faces must be sanded smooth (400–800 grit) or lathe-machined before applying the thin epoxy sealing coat to ensure a reliable seal.

### 3.4 Joint Reinforcement Strategy
Standard flat butt-joints glued together will fail under the cyclic bending and torsional moments caused by ocean wave action. If 3D printing, you must implement:
*   **Interlocking Joints**: Slices must use matching tongue-and-groove or male/female alignment collars.
*   **Tension Spars**: Run a central carbon-fiber tube (25mm diameter) or a stainless steel threaded rod along the length of each hull's centerline. Tensioning the end-caps onto this central rod squeezes the printed segments together in compression, ensuring wave bending forces are carried by the spar rather than the printed plastic seams.

```
       [Dome Cap] === [Segment 1] === [Segment 2] === [Dome Cap]
           ||============================================||
                    (Internal Tension Rod / Spar)
```

*   **Integrated Bulkheads**: The main advantage of 3D printing is the ability to print solid partition walls inside the model. Slicing the hull into 5 separate watertight bulkheads ensures that a single hull puncture only floods 20\% of the hull volume, preventing a total capsize.

### 3.5 Post-Machining (Turning) of 3D-Printed Parts
FDM parts printed in Nylon 12 (PA12) or Carbon-Fiber Nylon (PA12-CF) can be post-machined on a lathe to achieve high-precision clearances for O-ring grooves and bearing seats, provided the following parameters are maintained:
*   **Solid Stock Prep**: The area to be machined **must be printed with 100% solid infill** and a high wall perimeter count. If the cutting tool encounters a hollow infill cavity, the part will instantly tear and fail.
*   **Heat Management & Tooling**: Plastics have low melting points (PA12 melts at ~ 178°C). To prevent melting:
    *   Use **extremely sharp cutting tools** with high positive rake angles (HSS or highly polished carbide inserts designed for aluminum). Avoid dull tools or steel inserts.
    *   Set moderate spindle speeds (500–1000 RPM) but a **high feed rate** with a continuous, relatively deep cut. Scraping or taking too shallow of a cut will generate friction heat and gum up the tool.
    *   Apply compressed air or liquid coolant constantly to carry chips away.
*   **Layer Alignment & Shear Stress**: Printed parts are weaker along inter-layer seams. Minimize shear loads by taking light finishing passes (<= 0.2 mm depth of cut) and, if possible, orienting the print layers perpendicular to the lathe spindle axis.
*   **Abrasive Fillers (Carbon Fiber)**: If turning PA12-CF, standard HSS tools will dull in seconds. You **must use carbide tools** (or PCD diamond). Wear a respirator and use dust containment, as composite dust is a severe inhalation hazard.

---

## 4. Final Recommendation Summary

3D printing the hulls is **feasible but labor-intensive**. If you have the print capacity and workspace to handle epoxy coating, printing in **ASA** with a central tension spar offers the best buoyancy-to-weight ratio. 

However, from a reliability and engineering simplicity standpoint, switching to **SDR-35 PVC pipe** (commonly used for gravity sewer systems) is the superior compromise. It features a thin 6.1mm wall, weighs only 3.8 kg/m, is completely watertight, requires zero prints/seams, and maintains high impact resistance at a lower cost.

> [!CAUTION]
> **SDR-35 vs. Schedule 40 Sizing Trap**: When purchasing SDR-35 pipe, note that its outer diameter is **8.400 in (213.4 mm)**, whereas standard 8" Schedule 40 PVC has an OD of **8.625 in (219.1 mm)**. Standard Schedule 40 end caps will not fit SDR-35. Custom 3D-printed dome caps with a 213.4 mm ID must be fabricated, and all bracket/collar diameters in the OpenSCAD files must be scaled to `pvc_od = 213.4` to prevent clamping play.

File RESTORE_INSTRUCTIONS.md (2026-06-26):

# How to Restore Agent Conversations on a New Machine

This backup archive (`agent_conversations_backup.tar.gz`) contains the complete chronological record, artifacts, and logs of all your agent conversations. To restore them in a new environment:

### Step 1: Copy the Archive
Transfer the `agent_conversations_backup.tar.gz` file to the home directory of your target machine.

### Step 2: Create the Target Directory
Determine whether you are using the IDE client (`antigravity-ide`) or the CLI client (`antigravity`).
On the new machine, open a terminal and run the following command to ensure the local configuration and brain directory structure exists:

**For Antigravity IDE:**
```bash
mkdir -p ~/.gemini/antigravity-ide
```

**For CLI:**
```bash
mkdir -p ~/.gemini/antigravity
```

### Step 3: Extract the Archive
Run the following command to extract the conversation folders directly into the brain workspace:

**For Antigravity IDE:**
```bash
tar -xzf agent_conversations_backup.tar.gz -C ~/.gemini/antigravity-ide/
```

**For CLI:**
```bash
tar -xzf agent_conversations_backup.tar.gz -C ~/.gemini/antigravity/
```

### Step 4: Restore Conversation Databases (Optional)
If you have conversation metadata or databases/protos from another installation, copy them to the target `conversations` directory so that conversation history is indexed:

**For Antigravity IDE:**
```bash
cp -n ~/.gemini/antigravity/conversations/* ~/.gemini/antigravity-ide/conversations/
```

### Verification
Once extracted, all conversation IDs and their history logs will be available under the respective brain folder (e.g., `~/.gemini/antigravity-ide/brain/`) and loaded automatically upon initialization in the new environment.

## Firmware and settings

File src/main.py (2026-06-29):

#!/usr/bin/env python3
"""
Blue-Water Rover: Main Autopilot, Sensor Aggregator & Telemetry Server
Coordinates RC manual override, GPS waypoint navigation, depth obstacle avoidance,
and starts the Flask server to host the local HUD dashboard.
"""

import sys
import os
import time
import threading
import logging
from flask import Flask, jsonify, request, send_from_directory

# Include parent directory in search path to load comms modules
sys.path.append(os.path.dirname(os.path.dirname(os.path.abspath(__file__))))

from src.spektrum_rc import SpektrumRC
from src.drive_control import DriveControl
from src.navigation import NavigationController
from src.perception import RealSenseDetector
from comms.telemetry_handler import TelemetryHandler

logger = logging.getLogger("AutopilotMain")
logging.basicConfig(level=logging.INFO, format="%(asctime)s [%(levelname)s] %(message)s")

# Global Autopilot State
class AutopilotState:
    def __init__(self):
        self.mode = "MANUAL"       # "MANUAL" or "AUTO"
        self.cruise_throttle = 0.5  # 50% cruise speed
        self.battery_pct = 85.0
        self.battery_v = 51.2
        self.solar_w = 280.0
        self.prop_w = 0.0
        self.sys_w = 12.0
        self.killed = False

# Instantiate Flask App
hud_dir = os.path.join(os.path.dirname(os.path.abspath(__file__)), "hud")
app = Flask(__name__, static_folder=hud_dir)
state = AutopilotState()

# Control instances (Global references)
rc = None
drive = None
nav = None
perception = None
tel = None

@app.route("/")
def serve_index():
    return send_from_directory(hud_dir, "index.html")

@app.route("/<path:path>")
def serve_static(path):
    return send_from_directory(hud_dir, path)

@app.route("/api/telemetry", methods=["GET"])
def get_telemetry():
    """Compiles all telemetry fields to serve the HUD dashboard poller."""
    nav_state = nav.get_navigation_state() if nav else {}
    per_dists = perception.get_distances() if perception else {"left": 20.0, "center": 20.0, "right": 20.0}
    avoid_offset = perception.get_steering_offset() if perception else 0.0
    drive_state = drive.get_current_values() if drive else {"throttle_us": 1500, "rudder_us": 1500, "killed": False}

    # Simulate battery consumption and solar charging
    # Battery bank: 48V 115Ah (~5520 Wh).
    if not state.killed:
        # Calculate propulsion power based on current throttle us (neutral is 1500)
        throttle_fraction = abs(drive_state["throttle_us"] - 1500.0) / 500.0
        state.prop_w = throttle_fraction * 350.0  # Max power is 350W for single T200 thruster
        
        # Calculate net change (Solar - Prop - Systems)
        net_w = state.solar_w - state.prop_w - state.sys_w
        # Scale consumption per hour (divided by 36000 for 10Hz loop step)
        state.battery_pct = max(0.0, min(100.0, state.battery_pct + (net_w / (5520.0 * 10.0))))
        state.battery_v = 44.0 + (state.battery_pct / 100.0) * 8.0 # scale 44V to 52V
    else:
        state.prop_w = 0.0

    return jsonify({
        "mode": state.mode,
        "killed": state.killed or drive_state["killed"],
        "battery_pct": round(state.battery_pct, 1),
        "battery_v": round(state.battery_v, 2),
        "solar_w": round(state.solar_w, 1),
        "prop_w": round(state.prop_w, 1),
        "sys_w": state.sys_w,
        "net_w": round(state.solar_w - state.prop_w - state.sys_w, 1),
        
        # Navigation
        "lat": nav_state.get("lat", 0.0),
        "lon": nav_state.get("lon", 0.0),
        "cog": round(nav_state.get("cog", 0.0), 1),
        "sog": round(nav_state.get("sog", 0.0), 2),
        "target_bearing": round(nav_state.get("target_bearing", 0.0), 1),
        "distance_to_wp": round(nav_state.get("distance_to_wp", 99999.0), 1),
        "queue_len": nav_state.get("queue_len", 0),
        "gps_connected": nav_state.get("gps_connected", False),
        
        # Perception (RealSense D455)
        "closest_left": round(per_dists["left"], 2),
        "closest_center": round(per_dists["center"], 2),
        "closest_right": round(per_dists["right"], 2),
        "avoid_offset": round(avoid_offset, 2),
        
        # Actuation
        "throttle_us": drive_state["throttle_us"],
        "rudder_us": drive_state["rudder_us"],
        
        # Companion RC status
        "rc_connected": rc.is_connected() if rc else False
    })

@app.route("/api/command", methods=["POST"])
def post_command():
    """Handles commands sent from the HUD console (e.g. manual overrides, waypoints)."""
    data = request.json
    cmd = data.get("command", "").upper()
    
    if cmd == "KILL":
        execute_kill()
        return jsonify({"status": "accepted", "message": "Emergency kill triggered"})
    elif cmd == "RESET_KILL":
        state.killed = False
        if drive:
            drive.reset_kill()
        return jsonify({"status": "accepted", "message": "Emergency kill reset"})
    elif cmd == "AUTO":
        state.mode = "AUTO"
        return jsonify({"status": "accepted", "mode": "AUTO"})
    elif cmd == "MANUAL":
        state.mode = "MANUAL"
        return jsonify({"status": "accepted", "mode": "MANUAL"})
    elif cmd == "CLEAR_WP":
        if nav:
            nav.clear_waypoints()
        return jsonify({"status": "accepted", "message": "Waypoints cleared"})
    elif cmd == "ADD_WP":
        lat = data.get("lat")
        lon = data.get("lon")
        idx = data.get("index", 1)
        if nav and lat is not None and lon is not None:
            nav.add_waypoint(idx, float(lat), float(lon))
            return jsonify({"status": "accepted", "message": f"Waypoint {idx} added"})
        return jsonify({"status": "error", "message": "Invalid latitude/longitude"})
    
    return jsonify({"status": "error", "message": "Unsupported command"})


# Telemetry Uplink Callbacks (translating MeshCore ASCII commands)
def on_meshcore_wp(index_str, lat_str, lon_str):
    try:
        idx = int(index_str)
        lat = float(lat_str)
        lon = float(lon_str)
        if nav:
            nav.add_waypoint(idx, lat, lon)
            tel.send_packet(f"TEL:ACK,NAV:WP,INDEX={idx:02d},STATUS=ACCEPTED")
    except ValueError as e:
        logger.error(f"Uplink WP parse error: {e}")
        tel.send_packet("TEL:ERR,MSG=INVALID_WP_ARGS")

def on_meshcore_hold():
    logger.warning("Uplink command received: NAV:HOLD")
    state.mode = "MANUAL"
    if drive:
        drive.set_throttle(0.0)
        drive.set_rudder(0.0)
    tel.send_packet("TEL:ACK,NAV:HOLD,STATUS=LOITERING")

def on_meshcore_kill():
    logger.critical("Uplink EMERGENCY KILL received!")
    execute_kill()
    tel.send_packet("TEL:ACK,NAV:KILL,EMERGENCY_SHUTDOWN=ACTIVE")

def on_meshcore_req():
    send_telemetry_diagnostic()

def execute_kill():
    state.killed = True
    state.mode = "MANUAL"
    if drive:
        drive.kill()

def send_telemetry_diagnostic():
    """Generates and sends standard $TEL:DIAG frame over the serial channel."""
    if not tel:
        return
        
    nav_state = nav.get_navigation_state() if nav else {}
    lat = nav_state.get("lat", 0.0)
    lon = nav_state.get("lon", 0.0)
    sog = nav_state.get("sog", 0.0)
    q_len = nav_state.get("queue_len", 0)
    
    # Compile frame arguments
    bat = round(state.battery_pct, 1)
    sol = round(state.solar_w, 1)
    prop = round(state.prop_w, 1)
    op_state = "SHUTDOWN" if state.killed else ("CRUISING" if state.mode == "AUTO" else "LOITERING")
    throt_state = "ACTIVE" if (state.mode == "AUTO" and not state.killed) else "OFF"
    
    payload = f"TEL:DIAG,BAT={bat}%,SOL={sol}W,PROP={prop}W,LAT={lat:.5f},LON={lon:.5f},SPEED={sog:.1f}KT,STATE={op_state},THROTTLE={throt_state},WP_Q={q_len}"
    tel.send_packet(payload)


def run_autopilot_loop():
    """10Hz Autopilot Main Loop coordinating RC, nav navigation, and perception avoidance."""
    logger.info("Autopilot navigation loop thread started (running at 10Hz).")
    
    last_diagnostic_time = time.time()
    
    while True:
        loop_start = time.time()
        
        # 1. Update Mode from Spektrum RC Switch
        if rc and rc.is_connected():
            rc_auto = rc.get_auto_mode()
            if rc_auto and state.mode == "MANUAL" and not state.killed:
                logger.info("RC Switch toggled to Autonomous Mode.")
                state.mode = "AUTO"
            elif not rc_auto and state.mode == "AUTO":
                logger.info("RC Switch toggled to Manual Mode.")
                state.mode = "MANUAL"

        # 2. Compute Steering and Throttle Outputs
        if state.killed:
            # Force zero output if killed
            if drive:
                drive.kill()
        elif state.mode == "MANUAL":
            # Manual Mode: Map RC transmitter directly to actuators
            if rc and rc.is_connected():
                throttle = rc.get_throttle() # 0 to 1.0
                rudder = rc.get_rudder()     # -1.0 to 1.0
                if drive:
                    drive.set_throttle(throttle, dt=0.1)
                    drive.set_rudder(rudder)
            else:
                # RC signal lost in manual mode: stop motor, center rudder
                if drive:
                    drive.set_throttle(0.0)
                    drive.set_rudder(0.0)
        elif state.mode == "AUTO":
            # Autonomous Mode: Fuse navigation PID output and perception avoidance
            nav_rudder = 0.0
            if nav:
                nav_state = nav.get_navigation_state()
                nav_rudder = nav_state.get("rudder_cmd", 0.0)
            
            avoid_offset = 0.0
            if perception:
                avoid_offset = perception.get_steering_offset()

            # Fuse steering commands and clamp output
            target_rudder = nav_rudder + avoid_offset
            target_rudder = max(-1.0, min(1.0, target_rudder))
            
            # Autopilot cruise throttle
            target_throttle = state.cruise_throttle
            
            # Apply dynamic throttling based on safety factors
            # If obstacle in front is extremely close (< 4m), slow down or reverse
            if perception:
                dists = perception.get_distances()
                if dists["center"] < 4.0:
                    target_throttle = -0.2  # Dynamic reverse to back off
                elif dists["center"] < 7.0:
                    target_throttle = 0.15  # Slow down speed

            if drive:
                drive.set_throttle(target_throttle, dt=0.1)
                drive.set_rudder(target_rudder)

        # 3. Handle Telemetry Diagnostics
        # Send diagnostic packets every 5 seconds
        if time.time() - last_diagnostic_time >= 5.0:
            send_telemetry_diagnostic()
            last_diagnostic_time = time.time()
            
            # Periodically query telemetry watchdog
            if tel:
                tel.check_link_status()

        # Enforce exact 10Hz loop rate (0.1s step)
        elapsed = time.time() - loop_start
        sleep_time = max(0.01, 0.1 - elapsed)
        time.sleep(sleep_time)


def start_flask_server():
    """Starts the Flask server in a separate thread."""
    # Suppress verbose Flask console logs
    cli = sys.modules['flask.cli']
    cli.show_server_banner = lambda *x: None
    logging.getLogger('werkzeug').setLevel(logging.ERROR)
    
    logger.info("Starting local HUD web server on port 5000...")
    app.run(host="0.0.0.0", port=5000, debug=False, use_reloader=False)


if __name__ == "__main__":
    logger.info("Initializing Blue-Water Rover ASV Control Stack...")
    
    # 1. Initialize Spektrum RC satellite receiver
    rc = SpektrumRC(port="/dev/ttyAMA0")
    rc.daemon = True
    rc.start()
    
    # 2. Initialize Drive PWM Controller
    drive = DriveControl(throttle_pin=18, rudder_pin=19)
    
    # 3. Initialize GPS Navigation Controller (automatically defaults to sim if no serial)
    nav = NavigationController(port="/dev/ttyACM0")
    nav.daemon = True
    nav.start()
    
    # 4. Initialize RealSense Obstacle Detector (automatically defaults to sim if no camera)
    perception = RealSenseDetector()
    perception.daemon = True
    perception.start()
    
    # 5. Initialize MeshCore Telemetry Serial Handler
    tel = TelemetryHandler(serial_conn=None) # Mock serial for testing, parses internally
    tel.register_callback("NAV:WP", on_meshcore_wp)
    tel.register_callback("NAV:HOLD", on_meshcore_hold)
    tel.register_callback("NAV:KILL", on_meshcore_kill)
    tel.register_callback("TEL:REQ", on_meshcore_req)
    
    # Hook up telemetry lost safety callback (revert to manual / hold on signal loss)
    tel.register_heartbeat_lost_callback(on_meshcore_hold)

    # 6. Start Autopilot Thread
    autopilot_thread = threading.Thread(target=run_autopilot_loop)
    autopilot_thread.daemon = True
    autopilot_thread.start()
    
    # 7. Start Dashboard Web server
    start_flask_server()

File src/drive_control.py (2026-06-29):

#!/usr/bin/env python3
"""
Blue-Water Rover: Single Drive & Rudder PWM Controller
Manages hardware-timed PWM output for a single propulsion ESC and rudder servo.
Utilizes the pigpio library for jitter-free PWM, falling back to mock mode if unavailable.
"""

import time
import logging

logger = logging.getLogger("DriveControl")
logging.basicConfig(level=logging.INFO, format="%(asctime)s [%(levelname)s] %(message)s")

class DriveControl:
    def __init__(self, throttle_pin=18, rudder_pin=19, use_hardware_pwm=True):
        self.throttle_pin = throttle_pin
        self.rudder_pin = rudder_pin
        self.use_hardware_pwm = use_hardware_pwm
        
        # Calibration constants (in microseconds)
        self.THROTTLE_MIN = 1000    # Full reverse
        self.THROTTLE_NEUTRAL = 1500 # Stopped
        self.THROTTLE_MAX = 2000    # Full forward
        
        self.RUDDER_LEFT = 1100     # Maximum left deflection
        self.RUDDER_CENTER = 1500   # Center
        self.RUDDER_RIGHT = 1900    # Maximum right deflection

        # Slew rate limits (max change in pulse width per second)
        self.THROTTLE_MAX_SLEW = 500  # Takes 1 second to go from neutral to full forward

        # Internal state
        self.current_throttle_pulse = self.THROTTLE_NEUTRAL
        self.current_rudder_pulse = self.RUDDER_CENTER
        self.killed = False
        
        # Initialize pigpio connection
        self.pi = None
        if self.use_hardware_pwm:
            try:
                import pigpio
                self.pi = pigpio.pi()
                if not self.pi.connected:
                    logger.warning("Could not connect to pigpio daemon! Running in Mock Mode.")
                    self.pi = None
                else:
                    logger.info("Successfully initialized pigpio. Hardware PWM active.")
            except ImportError:
                logger.warning("pigpio library not found! Running in Mock Mode.")
                self.pi = None

        # Set default state to neutral
        self.apply_pwm()

    def set_throttle(self, target_fraction, dt=0.02):
        """
        Sets target throttle. Target fraction ranges from -1.0 (full reverse) to 1.0 (full forward).
        Applies slew rate limiting to prevent current spikes.
        """
        if self.killed:
            self.current_throttle_pulse = self.THROTTLE_NEUTRAL
            self.apply_pwm()
            return

        # Map target fraction (-1.0 to 1.0) to microseconds
        if target_fraction >= 0:
            target_pulse = self.THROTTLE_NEUTRAL + (target_fraction * (self.THROTTLE_MAX - self.THROTTLE_NEUTRAL))
        else:
            target_pulse = self.THROTTLE_NEUTRAL + (target_fraction * (self.THROTTLE_NEUTRAL - self.THROTTLE_MIN))

        # Clamp target pulse
        target_pulse = max(self.THROTTLE_MIN, min(self.THROTTLE_MAX, target_pulse))

        # Apply slew-rate limit to throttle
        max_change = self.THROTTLE_MAX_SLEW * dt
        diff = target_pulse - self.current_throttle_pulse
        
        if abs(diff) > max_change:
            direction = 1.0 if diff > 0 else -1.0
            self.current_throttle_pulse += direction * max_change
        else:
            self.current_throttle_pulse = target_pulse

        self.apply_pwm()

    def set_rudder(self, target_fraction):
        """
        Sets target rudder angle. Target fraction ranges from -1.0 (full left) to 1.0 (full right).
        No slew rate limit on steering to allow immediate wave reaction corrections.
        """
        if self.killed:
            self.current_rudder_pulse = self.RUDDER_CENTER
            self.apply_pwm()
            return

        # Map target fraction (-1.0 to 1.0) to microseconds
        if target_fraction >= 0:
            target_pulse = self.RUDDER_CENTER + (target_fraction * (self.RUDDER_RIGHT - self.RUDDER_CENTER))
        else:
            target_pulse = self.RUDDER_CENTER + (target_fraction * (self.RUDDER_CENTER - self.RUDDER_LEFT))

        # Clamp target pulse
        self.current_rudder_pulse = max(self.RUDDER_LEFT, min(self.RUDDER_RIGHT, target_pulse))
        self.apply_pwm()

    def apply_pwm(self):
        """Outputs current pulse widths to pins via pigpio or prints values in Mock Mode."""
        # Force neutral if killed
        if self.killed:
            self.current_throttle_pulse = self.THROTTLE_NEUTRAL
            self.current_rudder_pulse = self.RUDDER_CENTER

        throttle = int(self.current_throttle_pulse)
        rudder = int(self.current_rudder_pulse)

        if self.pi:
            try:
                self.pi.set_servo_pulsewidth(self.throttle_pin, throttle)
                self.pi.set_servo_pulsewidth(self.rudder_pin, rudder)
            except Exception as e:
                logger.error(f"Failed to set PWM pulse widths via pigpio: {e}")
        else:
            logger.debug(f"[MOCK PWM] Pin {self.throttle_pin}: {throttle} us | Pin {self.rudder_pin}: {rudder} us")

    def kill(self):
        """Emergency cutoff. Immediately resets both outputs to neutral and ignores further inputs."""
        self.killed = True
        self.current_throttle_pulse = self.THROTTLE_NEUTRAL
        self.current_rudder_pulse = self.RUDDER_CENTER
        self.apply_pwm()
        logger.critical("EMERGENCY KILL TRIGGERED! Drive outputs cut and locked at neutral.")

    def reset_kill(self):
        """Resets the emergency kill flag."""
        self.killed = False
        logger.info("Emergency kill reset. Normal control resumed.")

    def get_current_values(self):
        """Returns currently applied pulse widths."""
        return {
            "throttle_us": int(self.current_throttle_pulse),
            "rudder_us": int(self.current_rudder_pulse),
            "killed": self.killed
        }
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

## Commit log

2026-06-26 feat: add Option C design documentation and parametric PVC-to-extrusion mounting bracket script
    [pvc_extrusion_bracket.scad]
2026-06-26 feat: add rubber padding specification to vessel design and implement parametric 3D assembly model for Option A
    [asv_option_a_model.scad, pvc_extrusion_bracket.scad]
2026-06-26 docs: update pontoon hull specifications to SDR-35 PVC for weight optimization
2026-06-26 feat: add modular 3D-printed hull design and telemetry communication system
    [asv_option_a_printed_model.scad]
2026-06-27 feat: add ASV model options D and E with associated documentation and renders
    [asv_option_d_model.scad, asv_option_e_model.scad]
2026-06-27 feat: document Option F ASV configuration with new specification and visual assets
    [asv_option_f_model.scad]
2026-06-29 docs: upgrade avionics stack to three-tier compute architecture with multi-link telemetry and dual GPS-for-yaw system
2026-06-29 feat: add design documentation and 3D CAD models for magnetic coupling and potted wet-running propulsion systems
    [magnetic_coupling_drive_model.scad, potted_wet_drive_model.scad]
2026-06-29 docs: add pontoon print evaluation report and link it in vessel design docs
2026-06-29 docs: add post-machining guidelines for turning 3D-printed FDM parts
2026-06-29 docs: add machining and turning guidelines for 3D-printed and epoxy-potted components
2026-06-29 docs: document SDR-35 PVC dimensional sizing traps and required CAD adjustments for hull components
2026-06-29 feat: implement core navigation, GPS parsing, and PID controller with simulation capabilities
